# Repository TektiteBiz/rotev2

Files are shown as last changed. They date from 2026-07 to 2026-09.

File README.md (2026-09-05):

# RotEv2 FOC Library

## Install (PlatformIO)

Add to `platformio.ini`:

```ini
[env:myboard]
platform     = https://github.com/maxgerhardt/platform-raspberrypi.git
board        = generic_rp2350
board_build.core = earlephilhower
framework    = arduino
lib_deps     = https://github.com/TekiteBiz/rotev2.git
build_flags  = -std=gnu++17
```

---

## Dual-Core Contract

**The library owns core1.** The 24 kHz control ISR runs there and is started by `begin()`. Your
sketch runs on core0 (`setup()` / `loop()`).

**Do NOT define `setup1()` or `loop1()` in your sketch** — that conflicts with the library's core1
entry point.

---

## Quick Start

```cpp
#include <rotev.h>
using namespace rotev;

void setup() {
  Serial.begin(115200);
  begin();

  // 100 rad forward, cruising at 100 rad/s, reaching that in 0.5 s.
  Profile p = Profile::fromVelAccel(100.0f, 100.0f, 200.0f);
  p.print();

  motorEnable(MOTOR_1);
  motorSetProfile(MOTOR_1, p);
  ledColor(0, 0, 255);  // blue = running
}

void loop() {
  ProfileState st = motorProgress(MOTOR_1);
  Serial.printf("t %.2f s  pos %.1f rad  vel %.1f rad/s\n", st.t, st.pos, st.vel);
  if (st.done) ledColor(0, 255, 0);  // green = arrived
  delay(100);
}
```

See `examples/Basic/Basic.ino`.

---

## Profile

A `Profile` is a complete motion plan: a distance, and the velocity/acceleration envelope used to
cover it.

The shape is trapezoidal in velocity — constant acceleration up to the cruise speed, constant
speed, then constant deceleration back to rest — so position traces the familiar S. A move too
short to reach its cruise speed before it must start stopping degenerates to a triangle
(`cruiseTime() == 0`) at the same acceleration.

Distances are **signed**: a negative distance runs the move backwards. Velocity and acceleration
arguments are magnitudes.

### Constructing

```cpp
Profile();                                                        // empty, valid() == false
static Profile fromVelAccel(float distance, float max_vel, float max_accel);
static Profile fromTimeAccel(float distance, float time, float max_accel);
static Profile fromAccelDecel(float distance, float max_vel, float max_accel, float max_decel);
static Profile fromTimeAccelDecel(float distance, float time, float max_accel, float max_decel);
Profile scaleDistance(float k) const;
Profile scaleTime(float k) const;
```

- **`fromVelAccel(distance, max_vel, max_accel)`** — the usual one. Cover `distance` rad, never
  exceeding `max_vel` rad/s or `max_accel` rad/s². The duration falls out of the numbers.

  ```cpp
  Profile p = Profile::fromVelAccel(100.0f, 100.0f, 200.0f);  // ~1.5 s
  ```

- **`fromTimeAccel(distance, time, max_accel)`** — cover `distance` rad in exactly `time` seconds
  without exceeding `max_accel`. The cruise velocity is solved for. If `time` is shorter than the
  fastest move `max_accel` allows, you get that fastest move instead, and `duration()` is then
  larger than the `time` you asked for — check it if that matters.

  ```cpp
  Profile p = Profile::fromTimeAccel(100.0f, 2.0f, 200.0f);   // exactly 2 s
  ```

- **`fromAccelDecel(distance, max_vel, max_accel, max_decel)`** — the asymmetric complement to
  `fromVelAccel`: the ramp up runs at `max_accel` and the ramp down at `max_decel`. Useful when the
  axis can brake harder than it can drive (or the reverse). Passing the same rate twice reproduces
  `fromVelAccel` exactly.

  ```cpp
  Profile p = Profile::fromAccelDecel(100.0f, 100.0f, 100.0f, 400.0f);  // gentle start, hard stop
  ```

- **`fromTimeAccelDecel(distance, time, max_accel, max_decel)`** — the asymmetric complement to
  `fromTimeAccel`, with the same "too short a time gives you the fastest move instead" fallback.

  ```cpp
  Profile p = Profile::fromTimeAccelDecel(100.0f, 2.0f, 100.0f, 400.0f);
  ```

- **`scaleDistance(k)`** — vertical stretch of an existing profile. Same durations; distance,
  velocity, acceleration and deceleration all scale by `k`, so an asymmetric profile keeps its
  accel:decel ratio. A negative `k` reverses the move, which is how you build a return leg:

  ```cpp
  Profile back = p.scaleDistance(-1.0f);  // same envelope, opposite direction
  ```

- **`scaleTime(k)`** — horizontal stretch. Same distance; every duration scales by `k`, so
  velocity scales by `1/k` and both acceleration and deceleration by `1/k²`. `k` must be positive.

  ```cpp
  Profile gentle = p.scaleTime(2.0f);  // same move, twice as long, quarter the accel
  ```

### Multi-leg moves

```cpp
struct Leg {
  float dist;   // signed, rad
  float accel;  // magnitude, rad/s^2
  float decel;  // magnitude, rad/s^2
};

static bool fromLegs(const Leg* legs, int n, float time, Profile* out);
```

`fromLegs()` solves a whole sequence at once: it finds the single cruise velocity at which the legs,
run back to back, take exactly `time` seconds, and writes the resulting profiles to `out[0..n)`.
Each leg keeps its own accel and decel. Sharing one cruise velocity is what makes the sequence read
as one continuous move rather than n unrelated ones.

```cpp
const Leg legs[] = {{3.0f, 1.75f, 4.78f}, {7.0f, 1.0f, 1.75f}, {0.5f, 1.75f, 4.78f}};
Profile out[3];
if (!Profile::fromLegs(legs, 3, 9.9f, out)) { /* budget too tight -- see below */ }
```

```
leg1   3.00 rad v=1.3451 ta 0.769 tc 1.705 td 0.281  T 2.7554
leg2   7.00 rad v=1.3451 ta 1.345 tc 4.147 td 0.769  T 6.2611
leg3   0.50 rad v=1.1318 ta 0.647 tc 0.000 td 0.237  T 0.8835   <- pinned triangular
```

A leg too short to reach the shared velocity — leg 3 above, whose ramps meet at 1.132 rad/s — simply
runs flat out as a triangle and takes what it takes; the solver slows the other legs to absorb the
difference so the total still lands on the budget. Getting this wrong is subtle: a saturated leg's
duration stops responding to the cruise velocity entirely, so a solver that keeps crediting it with
the trapezoid formula lands a few milliseconds short.

The return value is **false** when `time` is below the flat-out total (every leg triangular at its
own limits). `out[]` is still filled, with that flat-out move — runnable, just slower than you asked
for — so you can check `duration()` to see what was actually possible. Degenerate input (`n <= 0`,
a null array, or a leg with a zero/non-finite distance, accel or decel) leaves every `out[]` entry
empty and returns false. Nothing is allocated; both arrays are caller-owned.

Bad arguments (zero, negative or non-finite distance/velocity/accel/time) produce an **empty**
profile rather than a fault: `valid()` is `false`, everything reads zero, and handing it to a
motor simply commands no motion.

### Querying

```cpp
float distance()    const;  // signed, radians
float duration()    const;  // seconds, accel + cruise + decel
float maxVelocity() const;  // signed peak (cruise) velocity, rad/s
float maxAccel()    const;  // signed peak acceleration, rad/s^2
float maxDecel()    const;  // signed peak deceleration magnitude, rad/s^2
float accelTime()   const;  // seconds
float cruiseTime()  const;  // seconds, 0 for a triangular profile
float decelTime()   const;  // seconds, == accelTime() only for a symmetric profile
bool  symmetric()   const;  // true when the two ramps take the same time
bool  valid()       const;  // false for an empty/degenerate profile
```

`maxVelocity()`, `maxAccel()` and `maxDecel()` carry the sign of the move, so they are the *actual*
peak values reached, not the magnitudes you passed in — for a triangular profile `maxVelocity()` is
below the `max_vel` you asked for. `maxDecel()` is a magnitude in the sense that the acceleration
actually reported during the ramp down is its negative: a profile decelerating at 400 rad/s² reads
`maxDecel() == 400` and `at(t).acc == -400` there.

### Sampling

```cpp
ProfileState at(float t) const;   // t clamped to [0, duration()]

struct ProfileState {
  float t;    // seconds since the profile started
  float pos;  // radians travelled (signed)
  float vel;  // rad/s (signed)
  float acc;  // rad/s^2 (signed)
  bool  done; // t >= duration()
};
```

`at()` evaluates the profile at any time without a motor being involved — useful for plotting or
for checking a move before committing to it. `t` is clamped, so `at(0)` is the start and any `t`
past the end returns the final position with zero velocity and `done == true`.

### Printing

```cpp
void print() const;
void printWithUnits(float wheel_radius, const char* unit) const;
```

`print()` dumps the profile to `Serial` in a readable block, in radians:

```
Profile: 100.000 rad in 1.500 s
  peak vel   100.000 rad/s (954.9 rpm) held 0.500 s
  peak accel 200.000 rad/s^2   peak decel 200.000 rad/s^2
  accel      0.500 s   cruise 0.500 s   decel 0.500 s
```

"held" is the time spent at peak velocity — the cruise time, `0.000` for a triangular profile.

`printWithUnits(wheel_radius, unit)` prints the same block converted to linear units, multiplying
every radian by `wheel_radius` and labelling it `unit`. The rpm figure is radius-independent and
stays. For a 16 mm wheel:

```cpp
p.printWithUnits(0.016f, "m");
```

```
Profile: 1.600 m in 1.500 s
  peak vel   1.600 m/s (954.9 rpm) held 0.500 s
  peak accel 3.200 m/s^2   peak decel 3.200 m/s^2
  accel      0.500 s   cruise 0.500 s   decel 0.500 s
```

An empty profile prints `Profile: <empty>` either way.

---

## Public API

All symbols are in `namespace rotev`. Include `<rotev.h>`.

### Initialization

```cpp
void begin();
```

Initializes GPIO, PWM, both ADCs, the LED and the buzzer, and starts the control loop on core1.
Call once from `setup()`.

### Motor

```cpp
void motorEnable(Motor m, bool enable = true);
void motorSetProfile(Motor m, const Profile& p);
Profile      motorProfile(Motor m);
ProfileState motorProgress(Motor m);
```

- **`motorEnable(m)`** — releases the driver's nSLEEP and lets the axis drive current. The axis
  then **holds position** even if it has never been given a profile: it is energised at standstill
  and resists being turned by hand. Standstill draws `MOTOR_HOLD_AMPS` (0.4 A), **not** the
  `MOTOR_AMPS` (0.9 A) a move uses — holding torque is therefore about 44% of moving torque.
  **If your application holds a load at standstill (a grade, a spring, a gripper, an arm), verify
  it still holds before updating: there is no position sensor, so a backdriven axis loses position
  silently and `motorProgress()` will still report the move completing normally.** Raise
  `MOTOR_HOLD_AMPS` in `constants.h` if your holding load needs it. There
  is no position sensor, so "position" means the commanded angle, which is 0 at boot — the first
  enable therefore pulls the rotor into alignment with electrical angle 0 rather than holding
  wherever it physically sits. `motorEnable(m, false)` zeroes the current and puts the driver back
  to sleep, leaving the shaft free.
- **`motorSetProfile(m, p)`** — starts `p` immediately, from wherever the axis currently is.
  Profiles are **relative**: the distance is measured from the position at the moment you call
  this, and the profile clock restarts at 0. Calling it again mid-move abandons the old profile
  and starts the new one from the current position. Setting a profile on a disabled motor stores
  it; it starts running when you enable the motor.
- **`motorProfile(m)`** — a copy of the profile currently executing.
- **`motorProgress(m)`** — where that profile is right now: elapsed time, position, velocity,
  acceleration, and whether it has finished. Poll `.done` to sequence moves.

When a profile finishes, the axis **holds**: velocity zero, angle frozen, still energised, so it
resists being pushed off target. Call `motorEnable(m, false)` to release it.

### LED

```cpp
void ledColor(uint8_t r, uint8_t g, uint8_t b);
```

Sets the RGB LED, 0–255 per channel (0 = off, 255 = full brightness).

### Buzzer

```cpp
void buzzerOn(uint16_t freq_hz);
void buzzerOff();
```

Drives the passive piezo buzzer at 50% duty. `freq_hz` is clamped to 1000–4000 Hz. Calling
`buzzerOn()` again while sounding retunes the frequency; you do not need `buzzerOff()` in between.

### Buttons

```cpp
bool buttonPressed(Button b);
```

`true` while the button is held.

### ADC and Bus Voltage

```cpp
float adcRead(AdcChannel ch);  // ADC_AIN1 / ADC_AIN2 / ADC_AIN3, volts
float busVoltage();            // volts
```

An on-board ADS1015 samples the motor bus voltage and the three user channels (AIN1–3) in the
background — there is nothing to start or poll. A timer started by `begin()` round-robins the four
channels, weighted so bus voltage refreshes at roughly 1 kHz (the control loop needs it) and each
user channel at roughly 330 Hz. Both calls return the most recent cached sample in volts and
are non-blocking.

### Enums

```cpp
enum Motor      : uint8_t { MOTOR_1 = 0, MOTOR_2 = 1 };
enum Button     : uint8_t { BTN_STOP = 0, BTN_GO = 1 };
enum AdcChannel : uint8_t { ADC_AIN1 = 0, ADC_AIN2 = 1, ADC_AIN3 = 2 };
```

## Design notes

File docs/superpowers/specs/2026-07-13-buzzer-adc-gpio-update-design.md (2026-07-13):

# RotEv2: Buzzer, ADS1015 ADC, GPIO Renumbering — Design Spec

**Date:** 2026-07-13
**Status:** Approved (brainstorming)
**Source PRD:** `docs/PRD.md` (updated 2026-07-13: buzzer, ADS1015 ADC, GPIO renumbering)
**Supersedes/extends:** `docs/superpowers/specs/2026-06-30-rotev2-foc-library-design.md`

## Overview

The PRD picked up three changes since the original FOC library design was implemented:

1. A passive piezo buzzer on GPIO4 (user on/off + frequency control).
2. An ADS1015 external I2C ADC (bus-voltage sensing for FOC inverse-park, plus
   3 user-facing channels).
3. GPIO renumbering: buttons/nSLEEP shifted by one pin, I2C1 (GPIO18/19) added
   for the ADC. Motor PWM pin naming/numbering (GPIO0-3) is unaffected — already
   correct in the current codebase.

This spec covers incorporating all three into the existing library structure
(`src/adc.cpp` = internal phase-current ADC stays as-is; a new `adc_ext.*`
module handles the ADS1015).

## Key Decisions

| Decision | Choice | Rationale |
|---|---|---|
| GPIO constants | Update `constants.h` only | No other file hardcodes raw pin numbers (verified). Mechanical change. |
| Buzzer PWM | Dedicated slice on GPIO4 (slice 2) | No aliasing with motor (slices 0/1) or LED (slices 4/7) slices. |
| ADS1015 driver | Single-shot mode, raw `hardware/i2c.h` on I2C1 @ 400kHz | Matches SDK-direct style used elsewhere in the codebase (no Arduino Wire). Single-shot gives explicit per-channel control needed for round-robin. |
| ADS1015 scheduling | Automatic background timer, not user-pumped | I2C1 is a dedicated bus (not user-facing — that's I2C0 on GPIO16/17), so there's no contention risk in making this fully automatic. Removes a footgun where a user forgets to pump a manual function and gets stale/wrong bus voltage feeding FOC. |
| Round-robin weighting | AIN0 (bus voltage): 2 of every 3 slots; AIN1/2/3 share the remaining slot in rotation | AIN0 effective rate ≈1.2-1.5kHz (meets "~1kHz" spec); user channels ≈150-250Hz each (ample for display/telemetry). |
| Vbus → FOC handoff | Same spinlock pattern as existing setpoint/telemetry cross-core state | Reuses proven mechanism; `controlStep` reads live `s_vbus` instead of constant `VBUS_V`. |
| Vbus startup fallback | Seed cache with nominal `VBUS_V` constant before first real sample | No special-cased startup logic needed in FOC; degrades gracefully. |
| User ADC API | `float adcRead(AdcChannel ch)`, returns cached volts, non-blocking | Matches existing telemetry-getter pattern (`motorCurrentA/B`). |
| Bus voltage API | `float busVoltage()` also exposed publicly | Needed by Phase 1 bringup to display/compare Vbus against a multimeter reading; also generally useful telemetry for any user sketch. |
| Buzzer API | `buzzerOn(uint16_t freq_hz)` / `buzzerOff()` | Frequency clamped [1000,4000]Hz; calling `buzzerOn` again while sounding retunes on the fly. |

## Architecture

### New/changed modules
- `constants.h` — updated pin numbers (`PIN_BTN_STOP=20, PIN_BTN_GO=21,
  PIN_NSLEEP_1=22, PIN_NSLEEP_2=23`), new `PIN_I2C1_SDA=18, PIN_I2C1_SCL=19,
  PIN_BUZZ=4`, new `AdcChannel` enum (`ADC_AIN1..3`).
- `src/buzz.h` / `src/buzz.cpp` (new) — PWM slice init/frequency retuning for GPIO4.
- `src/adc_ext.h` / `src/adc_ext.cpp` (new) — ADS1015 driver: init, background
  alarm callback + state machine, cached-value getters (`adcExtVbus()`,
  `adcExtUser(AdcChannel)`).
- `src/foc.cpp` — `controlStep` reads `adcExtVbus()` instead of the `VBUS_V`
  constant when computing `inversePark`/PI clamps. `VBUS_V` in `constants.h`
  becomes only the startup-fallback nominal value.
- `src/rotev.h` / `src/rotev.cpp` — new public functions: `buzzerOn`,
  `buzzerOff`, `adcRead`.
- `README.md` — updated GPIO/bus table, new Buzzer section, new ADC/AIN section.

### ADS1015 driver detail
- I2C1 @ 400kHz, raw `hardware/i2c.h` calls (`i2c_write_blocking`,
  `i2c_read_blocking` — each call is a few bytes, ~100-150µs, so blocking calls
  from within the alarm callback are acceptable and simple).
- Single-shot config per conversion: mux = target channel, PGA = ±4.096V FS
  (covers the 0-3.3V range of both the bus-voltage divider output and
  assumed user-signal range), data rate = 3300 SPS (fastest, ~303µs conversion).
- State machine (driven by a repeating hardware alarm on core0, registered in
  `adcExtInit()` called from `rotev::begin()`):
  - `START_CONV`: write 3-byte config register selecting the next channel in
    the weighted round-robin; record tick count.
  - `READ_RESULT`: once enough ticks have elapsed (≥ conversion time), read the
    2-byte conversion register, convert counts→volts, store into the
    appropriate cached slot (`s_vbus` for AIN0, `s_user[ch]` for AIN1-3) under
    the existing spinlock, advance round-robin, transition back to `START_CONV`.
  - Each alarm tick performs at most one of these steps — bounded, non-blocking
    from the caller's perspective (the alarm fires independently of user code).
- Round-robin sequence: `AIN0, AIN1, AIN0, AIN2, AIN0, AIN3, ...` (AIN0 every
  other slot = 2 of every 3 total slots across the 3-user-channel cycle).
- Counts→volts: `V = counts * (4.096 / 2048)` (single-ended 12-bit, ±4.096V FS
  in the ADS1015's 12-bit-left-justified single-ended convention).
- Bus voltage: `Vbus = adcExtVbus_divider_out * (7.3+2.2)/2.2` (undo the
  voltage divider) before caching into `s_vbus`.

### FOC integration
`controlStep()` (in `foc.cpp`) currently uses the compile-time `VBUS_V`
constant everywhere a bus voltage is needed (PI output clamps, `inversePark`
call). This changes to read `adcExtVbus()` once at the top of each
`controlStep()` invocation (a plain spinlock-guarded float read, same cost
profile as the existing setpoint read) and thread that value through instead
of `VBUS_V`. `VBUS_V` remains defined as the pre-ADC-sample fallback default.

## Public API additions (`namespace rotev`)
```cpp
void buzzerOn(uint16_t freq_hz);   // clamped to [1000, 4000] Hz, 50% duty
void buzzerOff();
float adcRead(AdcChannel ch);      // ADC_AIN1/2/3, last cached sample in volts, non-blocking
float busVoltage();                // last cached Vbus sample in volts, non-blocking
```
`AdcChannel` is a new enum in `constants.h`.

## Testing
- Buzzer: bringup smoke test (audible tone, frequency sweep) — no host-testable
  logic beyond clamping, which can get a small native unit test alongside the
  existing `test_foc_math` target.
- ADS1015 counts→volts and divider-undo math: pure functions, host-testable
  the same way as `foc_math`.
- Vbus feeding into FOC: validated on-hardware during bringup (compare
  measured Vbus via `adcRead`-style debug print against a multimeter reading
  of the actual bus rail).

## Documentation Deliverables
- `README.md` — updated GPIO/pin table (new button/nSLEEP/I2C1 numbers),
  new **Buzzer** section (range, API, 50% duty note), new **ADC** section
  documenting `adcRead()`, the 3 user channels, sample-rate expectations, and
  that bus-voltage sensing is automatic/internal (no user action needed).

## Bringup Impact (Phase 1)

Phase 1 (`bringup/phase1_hw.h`) is the first sketch to exercise the new hardware, so it gains two
additions:

- **Buzzer smoke test on GO:** pressing GO (in addition to turning the LED green) plays a short
  fixed tune via `buzzerOn`/`buzzerOff` calls (a few notes within the 1-4kHz range, each held
  briefly then silenced) before returning to the idle loop. This exercises the buzzer PWM path and
  gives an audible pass/fail signal without needing a scope.
- **Bus voltage telemetry:** the periodic serial print (alongside the four `motorCurrentA/B`
  traces) adds a fifth value, `rotev::busVoltage()`, so the operator can visually confirm it
  against a multimeter reading of the 12V rail.

`docs/BRINGUP.md` Phase 1 section (What to watch / Pass criteria / Failure modes table) is updated
to describe both additions.

## Open Assumptions to Confirm on Hardware
- ADS1015 I2C1 bus has adequate pull-ups on the PCB (dedicated bus, assumed
  fixed near the ADC — same assumption class as the existing I2C0 pull-up note
  in the PRD).
- PGA ±4.096V FS is adequate headroom for the bus-voltage divider output across
  the expected Vbus range; revisit if bringup shows clipping or poor resolution.

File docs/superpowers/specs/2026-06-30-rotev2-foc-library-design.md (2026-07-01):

# RotEv2 FOC Library — Design Spec

**Date:** 2026-06-30
**Status:** Approved (brainstorming)
**Source PRD:** `docs/PRD.md`

## Overview

RotEv2 is a PlatformIO/Arduino library for the Tektite RotEv2 PCB (RP2354 MCU). It
implements heavily optimized open-loop-position / closed-loop-current stepper FOC
for two 2-phase stepper motors, plus RGB LED and button support. It is published as
a conventional Arduino/PlatformIO library while internally using Pico SDK headers for
center-aligned PWM, timed ADC sampling, and dual-core scheduling.

## Key Decisions

| Decision | Choice | Rationale |
|---|---|---|
| Framework | earlephilhower arduino-pico core (import compatibility) with Pico SDK headers used internally | Users import as a normal Arduino/PlatformIO lib; internals get `<hardware/*.h>` for center-aligned PWM, ADC, DMA, IRQ. Verified RP2350/RP2354 (Pico 2) support. |
| Numerics | Single-precision `float` (M33 FPU) with standard `sinf`/`cosf` | Fast + readable; ~6200 cycles/loop @150 MHz vs a few hundred for trig. LUT only if bringup shows it doesn't fit. |
| Clock | Max validated clock; start 150 MHz, overclock target ~200 MHz confirmed in bringup | Timing constants derive from `clock_get_hz(clk_sys)`, never hard-coded. |
| Concurrency | FOC on **core1**, user code on **core0** | Real-time loop isolated from user code. Documented in README. |
| API style | Free functions in `namespace rotev` | Matches PRD examples; one fixed board. |
| ωe source | Differentiate commanded electrical angle + light LPF | Keeps `motorWrite(theta, current)` API exactly as PRD specifies. |
| Current sensing | INA186A3 (**100 V/V**), 15 mΩ shunt, REF 1.65 V → `V=1.65+1.5·I`, range ≈ ±1.1 A | Verified A3 = 100 V/V from TI datasheet. Current command clamped to ±1.1 A. |
| ADC oversampling | `ADC_OVERSAMPLE` default 4× per channel, burst centered on PWM midpoint | Rejects noise / boosts resolution while staying inside the center-aligned window (~16 µs burst). |
| Modulation | Direct αβ phase-voltage application via PH/EN (NOT SVPWM — that's 3-phase BLDC) | 2-phase stepper with two H-bridges; inverse-park voltages applied per phase. |
| LED polarity | Active-low (PWM on cathodes): pin high = off, pin low = on | Confirmed against board. |

## Hardware Reference

MCU: RP2354. GPIO map (from PRD):

| GPIO | Label | | GPIO | Label |
|---|---|-|---|---|
| 0 | ENA_2 | | 14 | LED.B |
| 1 | PHA_2 | | 19 | BTN_STOP |
| 2 | ENB_2 | | 20 | BTN_GO |
| 3 | PHB_2 | | 21 | nSLEEP_1 |
| 4 | ENA_1 | | 22 | nSLEEP_2 |
| 5 | PHA_1 | | 26 | SOB_1 (ADC0) |
| 6 | ENB_1 | | 27 | SOA_1 (ADC1) |
| 7 | PHB_1 | | 28 | SOB_2 (ADC2) |
| 8 | LED.R | | 29 | SOA_2 (ADC3) |
| 9 | LED.G | | | |

**User/bringup buses:**
- SPI1: GPIO10 SCK, 11 MOSI, 12 MISO, 13 CS — user-facing in production; **available for bringup debug**. `LOOP_TIMING_PIN` defaults to **GPIO10** during bringup.
- I2C0: GPIO16 SDA, 17 SCL — user-facing (board has pull-ups); not used in bringup.
- All bus pins may also serve as plain GPIO.

**Drivers:** Two motors, each with phase A and B. Each phase = one DRV8874 in PH/EN
mode + one INA186A3 inline current sensor (15 mΩ shunt, REF 1.65 V). `nSLEEP_1`
gates both motor-1 drivers; `nSLEEP_2` both motor-2 drivers.

**Motor (14HS11-1004):** 1.8°/step (200 steps/rev → **50 pole pairs**), phase R = 3.5 Ω,
L = 3.5 mH, rated 1.0 A.

**Buttons:** active-high, require internal pull-downs.

**RGB LED:** PWM on GPIO 8/9/14. **Active-low** — the PWM pins drive the LED
cathodes, so pin high = off, pin low = on. `LED_ACTIVE_HIGH = false`; a brightness
value of 255 = full on = pin held low (duty inverted internally).

## Architecture

### Packaging / layout
```
rotev2/
  library.json, library.properties, keywords.txt
  src/            rotev.h + internal modules
  examples/       short published usage sketches
  bringup/        self-contained PlatformIO project (lib_deps -> ../, own platformio.ini)
    phase1_hw/  phase2_openloop/  phase3_foc/  phase4_full/
  docs/PRD.md, docs/BRINGUP.md, docs/superpowers/specs/...
  README.md
```

### Modules (`src/`), each one focused unit
- `rotev.h` / `rotev.cpp` — public API (`namespace rotev`); thin, delegates to internals.
- `foc.*` — control loop: park / inverse-park, PI, lag comp. Runs on core1.
- `pwm.*` — center-aligned 24 kHz PWM setup; per-phase duty + direction (PH/EN).
- `adc.*` — ADC config, timed oversampled sampling, counts→amps.
- `hw.*` — pin map, `nSLEEP`, clock/overclock setup.
- `led.*` — RGB PWM.
- `button.*` — pull-down config + debounced reads.
- `debug.*` — `LOOP_TIMING_PIN` toggling (compile-time `ENABLE_LOOP_TIMING`).

### Dual-core model & data flow
- **core0:** user code + `rotev::` API.
- **core1:** real-time FOC; serviced by the 24 kHz PWM-wrap IRQ. Even/odd IRQs
  alternate motor 1 / motor 2 → **12 kHz per motor**.
- **Cross-core handoff:** `motorWrite` publishes `{theta, iq_cmd, enabled}` per motor
  into a shared struct; publication made atomic via an RP2350 hardware spinlock (or
  seqlock snapshot) so the ISR reads a consistent set. Telemetry (measured currents,
  estimated ωe) returns the same way for core0 logging/plotting.

## Control Loop

### PWM
- 4 phase EN pins → PWM slices, phase-correct (center-aligned), 24 kHz.
- `TOP = f_sys / (2 · 24000 · div)` (e.g. 3125 @150 MHz) → ~11–12-bit duty.
- One slice wrap IRQ = master 24 kHz tick on core1.

### Modulation (2-phase, direct αβ — NOT SVPWM)
SVPWM is a 3-phase BLDC technique and does not apply here. This is a 2-phase stepper
with two independent H-bridges: inverse-park yields the two phase voltages `Vα`
(phase A), `Vβ` (phase B) directly, and each is applied as a sinusoidal bipolar phase
voltage via `PH = sign(V)`, `EN duty = |V|/Vbus`. Open-loop phase current traces two
90°-shifted sine waves.

### ADC sampling
- Single SAR ADC, round-robin over the **active motor's two channels** only.
- Each channel sampled `ADC_OVERSAMPLE` (default 4×) in a tight burst, integer-
  accumulated then divided, then converted. Burst centered on the PWM midpoint (start
  ~half-a-burst before wrap so samples straddle center). ~16 µs @4×, inside budget.
  Drop to 2× if bringup shows the window too wide.
- `I = (counts/4095 · Vref − 1.65) / 1.5`; `Vref` isolated in one constant.

### Per-motor step (12 kHz, in ISR)
1. Read `Iα, Iβ` (measured; already αβ, no Clarke).
2. `θe = 50·θ_cmd`; estimate `ωe = 50·Δθ_cmd/Δt` with light LPF.
3. **Park** using commanded `θe` (open-loop position assumption) → `Id, Iq`.
4. **PI**: `kP = BW·L = 3.5`, `kI = BW·R = 3500` (BW = 1000 rad/s), anti-windup clamp.
   Setpoints `Id* = 0`, `Iq* = current command`.
5. **Lag comp**: `Uq = PIq(Iq*−Iq) + ωe·Ld·Id`, `Ud = PId(0−Id) − ωe·Lq·Iq`
   (Ld = Lq = 3.5 mH).
6. **Inverse Park** → `Vα, Vβ` → duty/PH. The 12 V bus assumption and all
   decoupling/feedforward live behind one `inversePark(Ud, Uq, θe, Vbus)` boundary so
   swapping in an ADC bus-voltage reading later is a one-line change.

Disabled motor: PI state reset, outputs zeroed, `nSLEEP` low.

### Debug timing pin
`LOOP_TIMING_PIN` (default GPIO10, bringup only) driven high on ISR entry, low on exit.
Scope it against PWM/current to measure per-loop compute time and sampling position.
`ENABLE_LOOP_TIMING` off in production frees the SPI1 pin.

## Public API (`namespace rotev`)
```cpp
void begin();                                   // clocks, pins, PWM, ADC, launch core1 FOC
void motorEnable(Motor m);                      // MOTOR_1 / MOTOR_2
void motorDisable(Motor m);
void motorWrite(float theta_rad, float amps, Motor m);   // position + q-current, amps clamped ±1.1A
void ledColor(uint8_t r, uint8_t g, uint8_t b);
bool buttonPressed(Button b);                   // BTN_STOP / BTN_GO
float motorCurrentA(Motor m), motorCurrentB(Motor m);    // last measured phase amps (telemetry)
```
`Motor` and `Button` are enums.

## Bringup (see `docs/BRINGUP.md` for full procedure)

Each phase is a sketch under `bringup/` with documented pass/fail vs scope/plotter.

- **Phase 1 — Basic HW:** enable/disable drivers, stream both phase currents, LED
  color on STOP/GO. *Pass:* sensible currents, buttons+LED respond, `nSLEEP` toggles.
- **Phase 2 — Open-loop SVPWM:** open-loop 60 RPM, voltage set for 0.1 A phase
  current; plot currents. *Pass:* two clean ~90°-shifted sine waves; timing pin shows
  stable 24 kHz.
- **Phase 3 — Closed-loop FOC (no lag comp):** PI current control, constant velocity /
  S-curve. *Pass:* Iq tracks setpoint, Id≈0, stable spin.
- **Phase 4 — Full library:** enable lag comp; S-curves to 100 rotations and 300 RPM.
  *Pass:* stable to 300 RPM, Id≈0 under speed (decoupling working), loop within budget.

## Documentation Deliverables
- `README.md` — library usage; full GPIO/bus map (incl. SPI1 GPIO10–13 & I2C0
  GPIO16–17); motor specs; PI tuning; current-sense range; dual-core note.
- `docs/BRINGUP.md` — phased procedure, what to look for, pass/fail.

## Testing
Real-time FOC validated on-hardware via bringup phases (no host harness for the ISR
path). Pure math helpers (park/inverse-park, scaling, ωe estimate) factored to be
host-testable for optional lightweight native tests.

## Open Assumptions to Confirm on Hardware
- Overclock target (~200 MHz) stability.

**Resolved:** ADC `Vref` = 3.3 V (confirmed); LED active-low with PWM on cathodes
(confirmed); modulation is direct αβ phase-voltage application, not SVPWM (confirmed).

## Workflow (per CLAUDE.md)
Feature branch, pre-feature tag, commit spec, per-phase validation against ground
truth before advancing; no direct work on `main`.

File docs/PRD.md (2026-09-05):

# rotev2 PRD
RotEv2 is a PlatformIO library meant specifically for the Tektite RotEv2 PCB and implements heavily optimized open-loop stepper FOC for both motors.

# Hardware
The library has 3 main functions exposed to the user:
- Stepper FOC control (via the drivers and current sensors)
- RGB LED
- Button detection
Documentation must be written in README.md outlining each function and explaining its use as well as the user-exposed GPIOs.

## MCU
MCU: RP2354
GPIO mappings: (GPIO #: label)
- 0: PWMA_2
- 1: PWMB_2
- 2: PWMA_1
- 3: PWMB_1
- 4: BUZZ
- 8: LED.R
- 9: LED.G
- 14: LED.B
- 18: I2C1_SDA
- 19: I2C1_SCL
- 20: BTN_STOP
- 21: BTN_GO
- 22: nSLEEP_1
- 23: nSLEEP_2
- 26: SOB_1
- 27: SOA_1
- 28: SOB_2
- 29: SOA_2

## Drivers
There are two stepper motors (motor 1 and motor 2). Each motor has phases A and B. Each phase has a DRV8874 motor driver set up with PH/EN mode, and a current sensor which is a INA181A2 with a 30mohm shunt and with REF biased to 1.65V. SOB_1 is the current output of the B phase of motor 1.

Each driver's EN pin is hardwired HIGH (pull-up on the PCB, no MCU connection) rather than GPIO-controlled. PH is driven by PWM (locked-antiphase: duty=(1+d)/2, d in [-1,1]), so current is always actively driven through the H-bridge rather than coasting -- this is the decay behavior FOC needs. For example, PHB_2 is the PWM pin on the B phase driver for motor 2. This replaced an earlier sign-magnitude scheme (EN-PWM, PH as static direction) that coasted instead of actively decaying; see Known Pitfalls.

nSLEEP is connected between each pair, so both drivers for motor 1 share nSLEEP_1 and both drivers for motor 2 share nSLEEP_2

## Buttons
The buttons go HIGH when pressed, so need the internal pull-down. 

## Buzzer
There is a passive piezo buzzer with a range of 1k-4khz on the BUZZ pin, apply a 50% duty cycle and adjust frequency. Make this user facing so the user can turn on and off the buzzer and set the frequency.

## RGB LED
The RGB LED will be controlled via PWM with the 3 pins. 

## Additional GPIOs
GPIOs 10, 11, 12, and 13 are meant for use by the user, but will also be used during bringup (explained later). These pins are the SPI1 bus, which must be documented in the readme. GPIOs 16 and 17 are I2C0 and feature I2C pull-ups on the board and are also exposed (but not used for bringup) and also must be documented in README.md. These pins serve as busses for the user but can also be used as general GPIO and not exclusively for SPI/I2C. The mappings when being used as a bus are as follows:
- 6, 7: General GPIO (PWM-capable)
- 10: SCK
- 11: MOSI
- 12: MISO
- 13: CS
- 16: SDA
- 17: SCL
- 24, 25: General GPIO, cannot do PWM since overlaps with LED PWM slice

## ADS1015 ADC
On I2C1 (GPIO 18/19) there is an ADS1015IRUGR ADC. AIN0 on this ADC is connected to bus voltage with a voltage divider with 7.3kohm on the high side and 2.2kohm on the low side. This needs to be sampled at ~1khz for the FOC loop inverse park. AIN1-3 are exposed to the user so consider how to display them to the user too.

The driver samples in a repeating-timer callback doing blocking I2C. Measured
in service the bus reads 12.12-12.17 V with a 0.07 V spread, i.e. neither sag
nor meaningful sampling noise, so the live value behaves like the 12.0 V
constant it replaced. Two caveats worth keeping in mind: the I2C return codes
are currently ignored, so a failed transaction writes uninitialised stack into
the cached voltage; and a bus voltage of 0 (drivers unpowered) sends
inversePark down its `inv = 0` path and trips the voltage backstop, so the FOC
is silently inert with driver power off.

# FOC
High frequency FOC will be implemented and run. The specifications are:
- 24kHz PWM frequency (with 12kHz control loop for each motor, alternating between motor 1 and motor 2)
- Need to be able to disable the control and each driver via nSLEEP (e.g. motorEnable(MOTOR_1) type of thing)
- The caller does not command position, velocity or current directly. It hands
  the ISR a motion PROFILE and the ISR executes it (`motorSetProfile(m, p)`).
  The profile computation has to happen inside the FOC tight loop: a commanded
  field generated on core0 is only as fine as the caller's loop rate and
  freezes for the whole of any caller stall, which lands directly on the field
  as torque ripple. Generating it on the hardware-timed control tick removes
  the caller's timing from the picture entirely.
- `Profile` (see `src/profile.h`) is trapezoidal in velocity -- constant
  acceleration to a cruise speed, then constant deceleration -- so the position
  it integrates to is the S curve. It is constructible from distance plus max
  velocity and acceleration, from distance plus a target time and acceleration,
  or by scaling an existing profile's distance or time.
- Current is fixed internally at `MOTOR_AMPS` (0.9 A) for moves and `MOTOR_HOLD_AMPS` (0.4 A) at standstill. Neither is exposed.
- The caller can read back the active profile (`motorProfile`) and its progress
  -- time, position, velocity, acceleration, done (`motorProgress`).
- Telemetry needed for bringup and tuning: per-motor phase currents, dq
  currents and applied dq voltages, plus live bus voltage. Without dq
  telemetry the loop is effectively unobservable -- see Known Pitfalls. This
  is not part of the user-facing API; it lives in `src/rotev_internal.h`.

Implementation-wise, there must be
- Center aligned PWM for SVPWM
- No clarke transform is needed since the currents are already in alpha-beta frame
- For park transform, assume the rotor is at the target position, and run PI control
- Run PI with pole placement, PER AXIS (the machine is salient, so a single
  gain cannot place both poles):
kP_d = BANDWIDTH * Ld
kP_q = BANDWIDTH * Lq
kI   = BANDWIDTH * R      (SHARED between the two axes)

kI is deliberately not split. Each axis must place its controller zero on its
own plant pole: the d-axis plant is 1/(Ld*s + R) with a pole at -R/Ld, so the
zero belongs at kI/kP_d = R/Ld, which falls out of kP_d = BW*Ld with a shared
kI = BW*R. The same holds for q. The saliency lives entirely in kP.

The motor specs are follows (write this in README):
- Part No: 14HS11-1004
- Step Angle: 1.8deg
- Phase Resistance: 3.5ohms  (datasheet -- WRONG, see below)
- Inductance: 3.5mH          (datasheet -- WRONG, see below)

### Measured motor parameters (these supersede the datasheet)

Both datasheet figures are wrong, and the inductance is wrong by more than 2x
in the direction that costs top speed. Bringup phase 5 measures them on real
hardware. The values below are the mean of two motors, which agreed to within
1.6% on R, 1.5% on Ld and 3.6% on Lq.

| Parameter | Measured | Datasheet |
|---|---|---|
| R (winding + Rds(on) + shunt) | 4.0417 ohm | 3.5 |
| Ld | 3.7946 mH | 3.5 |
| Lq | 8.2764 mH | 3.5 |
| saliency Lq/Ld | 2.16 - 2.20 | not given |

**The machine is salient.** Lq is ~2.2x Ld, which is expected for a hybrid
stepper -- the magnet sits in the d-axis flux path with mu_r ~ 1, making d the
high-reluctance axis -- but it means one inductance constant cannot describe
both axes. The datasheet's 3.5 mH is roughly Ld; nobody published Lq, and Lq
is the one that governs high-speed behaviour.

**Lq falls with current** (iron saturation), roughly 8.3 mH at 0.5 A trending
toward 6 mH at 1.0 A. The runtime therefore does not trust the constant: it
maintains a per-motor ONLINE Lq estimate from |ud|/(we*|iq|). PHASE_LQ only
seeds that estimate and sets kP_q and the decoupling feedforward.

**lambda_m (magnet flux) is NOT reliably measured.** The phase 5 extraction
returns a negative value with poor fit quality on both motors, and the two
motors disagree by 10x on it while agreeing to within 4% on everything else --
so the method is broken, not the motors. Do not use the printed Kt. Two
independent facts bound it instead: the 1700 RPM ceiling requires
lambda_m <= 0.67 mWb, hence Kt <= 0.033 N.m/A. That is far below what the
datasheet holding torque suggests, and it explains why the drive runs out of
torque so readily at low current.

Use the resistance and inductances for the PI tuning above.
Use bandwidth = ~160 Hz (so 1000 rad/s)

### Cross-coupling decoupling ("lag compensation")

Ud_compensation = −ωe · Lq · Iq
Uq_compensation = +ωe · Ld · Id

So in the end:
Uq = PIq(Iq_setpoint − Iq_measured) + ωe·Ld·Id_setpoint
Ud = PId(0 − Id_measured) − ωe·Lq·Iq_setpoint

**Feed these from the current COMMAND, never the measurement.** Using measured
Id/Iq closes a loop Ud -> Id -> Uq -> Iq -> Ud whose gain is
(we*Lq)(we*Ld)/(Zd*Zq); at speed Zd -> we*Ld and Zq -> we*Lq, so the gain
approaches exactly 1 -- marginally stable before the pipeline delay is even
counted -- and it multiplies current-sense ripple by we*Lq, which is 30 V/A at
690 RPM. Measured on hardware: the measured-current form dropped the ceiling
from 690 RPM to 550 RPM. Since Id_setpoint is always 0, only the d-axis term
survives in practice.

Note *why* this is needed, because it is not the usual reason. As a
DISTURBANCE the coupling is DC in the dq frame and the integrator rejects it
almost perfectly (~0.5 mA of error through a 2 s ramp), so deleting it looks
harmless at low speed and did in fact pass review once on that argument. It
matters because it couples the two regulators DYNAMICALLY: once we exceeds
BANDWIDTH the axes drive each other faster than either loop can respond. The
signature is unmistakable -- phase currents that are garbage while spinning
and a perfect sine the instant the rotor is stopped and we goes to zero.

Implement a tight loop with proper ADC sampling timing, proper center-aligned PWM, etc.

## Voltage limit, current derate, and the speed ceiling

On a 12 V bus this drive runs out of VOLTAGE long before it runs out of
current, and ud is what consumes it:

    ud = -we * Lq * iq          (uq measured only 0.8 V at 300 RPM, and falling)

The only lever on ud is iq, so the correct response to running out of voltage
is to command LESS CURRENT, not to throw torque away. Each control cycle:

    iq_max = UD_FRAC * vbus / (|we| * Lq_online) * trim   UD_FRAC = 0.83

This trades current for speed automatically, so the drive rides the voltage
limit rather than falling off it, and no hand-tuned current-per-speed table is
needed.

**The limit must be feedforward from speed, not feedback from measured ud.**
piStep already clamps its output to +-vbus, so |ud| can never be *observed*
exceeding the bus and a feedback version can never derate by more than
(1 - UD_FRAC). Measured on hardware: a feedback derate targeting 0.85 of the
bus actually delivered 0.995 and sat pinned at the backstop continuously.

A backstop still clamps |u| to vbus, scaling ud and uq TOGETHER so the applied
vector keeps its angle (an earlier version zeroed uq outright, which removed
all torque at exactly the speed where torque was needed and turned the ceiling
into a cliff). It must also pull the PI integrators down by the same factor:
piStep's anti-windup only sees its own per-axis +-vbus limit and cannot
observe the later scaling.

**The |u| <= vbus circle is correct here, not conservative.** Two independent
H-bridges do give a square limit reaching sqrt(2)*vbus on the diagonals, but
for a ROTATING vector va = |u|*cos(theta+phi) sweeps the full amplitude every
cycle, so |va| <= vbus requires |u| <= vbus. The square only helps a
stationary vector. The remaining lever on voltage is overmodulation (the
square-wave fundamental reaches 4/pi * vbus, ~27% more, at the cost of
deliberate harmonics), not a different clamp shape.

Measured behaviour: speed and current trade directly, rpm_max * iq ~= 280 at
0.5 A rising to ~370 at 1.0 A (the product is not constant because Lq
saturates). Lower current is monotonically faster until torque runs out;
below ~0.3 A the motor is torque-limited instead. With the derate active the
drive reached **1700 RPM**, against ~400 RPM before the parameters were
corrected.

## Control delay compensation

Current is sampled at the top of the ISR; the duty computed from it is applied
at the NEXT ISR for that motor and then held for a full tick, so the voltage
lands ~1.5 ticks after the measurement. At 700 RPM that is 125 us = 26
electrical degrees of stale angle, which rotates the applied vector backwards
and visibly distorts the phase currents. The inverse Park therefore runs at
theta_e + we*COMP_TICKS*dt, while the forward Park stays at the angle the
sample was actually taken at.

## Control-rate limit

The commanded field advances in steps of
(rpm/60)*360*POLE_PAIRS/(PWM_HZ/2) electrical degrees -- i.e. **rpm/40** at
24 kHz. FOC generally wants 20+ updates per electrical cycle; at 1700 RPM
there are only 8.5, which is why the current cannot look like a clean sine up
there regardless of voltage headroom. The only lever is PWM_HZ, traded against
ISR budget.

## Bringup
- The board will be brought up in phases (so make some test programs as a sub-folder that reference the library in the exterior folder that can be deployed to the board, can use development environments but it shouldn't interfere with the libraries use as a library)

### Phase 1: Basic hardware
Enable & disable motor drivers, log current sensing, change RGB LED color when stop/go pressed, etc. - no motion, just reading the sensors and ensuring basic hardware functionality

### Phase 2: Open-loop control
Do open-loop SVPWM with a voltage such that the phase current is 0.5A and spin the motors at 60RPM open-loop. Still log phase current and let it be graphed via arduino serial plotter. Should show up as two sine waves

(Originally spec'd at 0.1A -- raised to 0.5A after bringup showed 0.1A doesn't give
enough torque to overcome this motor's detent/static friction, so it just buzzes in
place instead of rotating even with a correct startup ramp. See Known Pitfalls.)

### Phase 3: Simple closed-loop FOC
Enable the PI controllers, constant velocity, on BOTH motors. Runs one long
profile whose cruise phase dominates, so the axis spends minutes at speed.

Because there is no position sensor, the loop park-transforms the measured
current onto the COMMANDED angle -- which is false at power-up, when the real
rotor angle is arbitrary. The velocity ramp from zero resolves this on its
own: for its first moments the commanded field is barely moving while already
carrying full current, which is exactly an alignment hold, and the rotor is
captured long before the speed is high enough to outrun it. A separate
explicit align stage was tried and removed as redundant.

Holding a stationary field at a known current is still the right way to check
the current-sense GAIN, since with the rotor still there is no back-EMF and no
di/dt and uq reduces to Ohm's law (`I_actual * R + V_offset`). That comparison
is what verified this board's sense chain to 0.3%, and it is worth repeating
on any new board before trusting a current number -- phase 5's alignment stage
does exactly this as its first step.

Logs loop rate, worst-case loop dt, electrical degrees per field step, bus
voltage min/max, and per-motor sensA/sensB/ud/uq/id/iq/derate.

### Phase 4: Full library
Trapezoidal position profile to 100 rotations on BOTH motors, peak 400 RPM,
via `motorSetProfile` (position authoritative + velocity feedforward).
Exercises the decoupling, the voltage derate and the delay compensation
together under acceleration.

### Phase 5: R / Ld / Lq characterization
Measures the motor parameters the datasheet gets wrong. Open-loop voltage
(`focSetVoltageAB`, no PI in the path) plus the existing current sense.

- **R** -- 6-point V/I sweep regressed as I vs V. Using the SLOPE rather than
  any single V/I point makes it immune to current-sense offset and to the
  driver's fixed dead-time drop; both land in the intercept, which is reported
  separately as a diagnostic.
- **Ld** -- step response with the rotor parked by DC current on phase B,
  which makes B the d-axis so the step produces zero torque and the rotor
  cannot move. Fitted by weighted least squares on ln(residual) vs t: the
  SLOPE carries tau, so the (variable, ~125 us) pipeline delay lands in the
  intercept and cancels. Weighting by r^2 and cutting the window at r > 0.15
  removes the Jensen bias of the log transform; 16 averaged captures take the
  spread to ~0.2%. Verified in simulation before being written to firmware.
- **Lq** -- CANNOT be measured at standstill: any q-axis current makes torque
  and the rotor moves, and it cannot be restrained by hand (the locked-rotor
  attempt returned R^2 0.95 with R_step 19% high). Measured instead on the
  SPINNING machine, where id is held at 0 and ud = -we*Lq*iq is a straight
  line through a 100-300 RPM sweep. R^2 0.9999.

Self-checks printed: R from the sweep vs R from the step (should agree to
~1%), fit R^2 for each, both regression intercepts (should be ~0), per-point
id during the speed sweep (off-zero means lost sync), and a raw CSV dump of
the averaged step captures so the exponential can be eyeballed.

Run from cold: the routine dissipates enough to warm the winding, and R
measurably tracks temperature at +0.39%/degC.

Document library use properly in README.md. Do everything with the consideration that this repository will be published as a platformio library.

## Known Pitfalls (learned during bringup)

These are hard-won findings from real hardware debugging. Read before touching PWM/GPIO init code.

### `pwm_set_mask_enabled()` overwrites the WHOLE PWM enable register
`pwm_hw->en` is a single register shared by every PWM slice on the chip (not per-slice). The
pico-sdk's `pwm_set_mask_enabled(mask)` does `pwm_hw->en = mask` — a blind overwrite, not a masked
set. If you build a mask containing only "the slices I care about" and call this, you will
silently **disable every other slice already running**, including the LED's PWM slices (GPIO
8/9 share slice 4, GPIO 14 is slice 7) if `ledInit()` ran first. This exact bug caused the RGB LED
to go stuck full-brightness ("white") the instant `focStart()`/`pwmInit()` ran, even though the
LED code itself was untouched and correct — it looked like an LED bug for a long time but was a
motor-PWM-init bug with an LED-shaped symptom. Always OR your mask into the existing register
(`pwm_hw->en |= mask;`) instead of overwriting it, so unrelated slices are left alone.

### GPIO-to-PWM-slice aliasing is real and easy to miss
Slice number = `(gpio >> 1) & 7` (for gpio < 32), channel = `gpio & 1`. Two GPIOs 16 apart, or an
even/odd pair like 8/9, can land on the *same* slice as different channels. `PIN_LED_R` (8) and
`PIN_LED_G` (9) are one such pair. `pwm_init()` resets the whole slice's counter-compare register
(both channels) every time it's called — so if two aliased pins are each `pwm_init`'d
independently, the second call clobbers the first pin's compare value. Init each unique slice
exactly once; only touch channel levels afterward via `pwm_set_gpio_level`/`pwm_set_chan_level`
(masked read-modify-write), never by re-running `pwm_init` on an already-configured slice.

### Diagnosing "firmware says X but hardware shows Y": read the actual registers
When a symptom contradicts what the code should be doing, don't keep guessing at the source —
print the raw peripheral registers (e.g. `pwm_hw->slice[N].csr`, `.cc`) directly over serial. This
is what actually found the enable-register bug above, after multiple plausible-sounding
software theories (LED slice aliasing, brownout/reset loops, hardware damage) were all
individually ruled out by hardware evidence and would have kept wasting time otherwise.

### `gpio_set_function(pin, GPIO_FUNC_PWM)` silently overrides an earlier SIO setup
`cfgSlice()`/`cfgEn()`-style helpers that call `gpio_set_function(pin, GPIO_FUNC_PWM)` change
*that specific pin's* mux, independent of anything `hwInit()` did earlier (`gpio_init` +
`gpio_set_dir` + `gpio_put`). During the first locked-antiphase experiment, a helper was reused
for its slice-init side effect on a pin that was supposed to stay a static GPIO output (motor 1's
EN pin, meant to be held HIGH) — but the helper also flipped that pin's own function to PWM with
its compare register left at 0 (permanent 0% duty), silently overriding the earlier `gpio_put(...,
1)`. Symptom: driver outputs stayed Hi-Z (disabled) the whole time — felt like inert detent
"braking" under hand rotation, not actual holding torque, with current telemetry reading ~0. Fix:
never assume a pin keeps whatever GPIO function `hwInit()` gave it — if a later init step touches
that pin's slice for any reason, explicitly re-assert the function/level you actually want
afterward, or (better, as done in the final design) restructure so nothing ever needs to touch a
pin's function twice with conflicting intents.

### A `volatile` struct field that is never copied out reads as stack garbage
`controlStep()` snapshots the shared `Setpoint` into a local under the spinlock,
one field at a time. Two fields (`ab_mode`, `vb_duty`) were never assigned — and
because the local is uninitialised, `if (sp.ab_mode)` was testing whatever was on
the stack. It consistently read false, so the direct-duty branch never ran and
execution silently fell through to the closed-loop PI, which then interpreted
`iq_cmd` as an amps command when the caller had stored a *duty* there. Every
caller of that mode commanded zero current and got zero current: phase 1c had
never worked as designed, and phase 5 initially reported `R = -72785 ohm`
because every point in its sweep measured no current at all. The user-visible
symptoms — nothing felt on the shaft, no supply draw — were the diagnosis; the
numbers were just an honest reading of a winding carrying nothing. Worth noting
this also invalidated the `ISENSE_SCALE` sign calibration, which had been
performed with phase 1c. When adding a field to a struct that is snapshotted
field-by-field, add the copy in the same commit, and prefer initialising the
local so a missed field fails loudly rather than plausibly.

### The setpoint refresh rate, not the ISR rate, quantizes the commanded field
The control ISR can only act on the angle the caller last handed it, so the
commanded field advances in steps of `(rpm/60)*360*POLE_PAIRS*T_caller`. A
`delayMicroseconds(500)` in the bringup loop meant 528 us per iteration, which
at 500 RPM is a **79 degree** electrical jump per update — a quarter cycle at a
time, not a rotating vector. It was plainly audible as clicking and roughness,
and it eats pull-out margin because the instantaneous load angle swings by half
the step. Deleting one delay line took the step to the ISR-rate floor of 12.5
degrees and the motor went "basically silent". Note the winding is a low-pass
(tau = L/R ~ 1 ms) so the *current* still looks like a decent sine while the
*command* is a coarse staircase — the scope will not show you this.

### The current waveform cannot tell you whether the rotor is turning
With no position sensor, the loop parks measured current onto the COMMANDED
angle, so the regulator produces a textbook rotating current vector whether the
rotor follows or sits dead still. It looks *better* when stalled, because a
stationary rotor generates no back-EMF and `uq` only has to supply `R*iq`. A
perfect sine at 400 RPM is therefore fully consistent with a stalled motor. Use
`uq` as the discriminator: back-EMF exists only if the rotor is moving, so a `uq`
near `R*iq` means stalled regardless of how clean the phase currents look. Hours
were spent debugging a current loop that was working correctly the whole time.

### Unbounded float angle accumulation stalls silently as the loop gets faster
`theta` accumulated without wrapping. Float resolution scales with magnitude, so
once theta passes ~5000 rad the per-iteration increment (2.6e-4 rad at 500 RPM
with a 5 us loop) vanishes into rounding entirely and the motor quietly stops
advancing. It was safe only because the loop was slow enough that the increment
was 100x larger — speeding the loop up is exactly what triggers it. `POLE_PAIRS`
is an integer, so wrapping mechanical angle at 2*PI is exactly 50 whole
electrical cycles and leaves `electricalAngle()` bit-for-bit unchanged. Phase 4's
profile position needs `double` for the same reason: its 628 rad target is where
float resolution (6e-5) approaches one iteration's increment.

### A clamped signal cannot be used as the feedback for a limiter
A current derate was built as feedback on `|ud|`, scaling the command by
`ud_lim/|ud|`. It could not work: `piStep` already clamps its output to
`+-vbus`, so `|ud|` never *exceeds* the bus and the ratio could never drop below
`UD_FRAC` — structurally incapable of derating more than 15% no matter how far
over budget the drive really was. Symptom: at 0.8 A it delivered 0.68 A where
~0.29 A was needed, and the ceiling barely moved. Before closing a loop around a
measurement, check whether anything upstream saturates it.

### Clamping after the regulator winds up integrators it cannot see
The `|u| <= vbus` backstop scales `ud`/`uq` *after* `piStep`, whose anti-windup
only knows its own per-axis limit. With `ud = -12.10` inside `+-12.16` the PI
believed it was unsaturated and kept integrating against a ceiling it had no way
to observe, while the applied voltage sat pinned at `|u| = vbus` continuously.
Any post-hoc actuator clamp has to be reported back to the regulator.

### Feedforward decoupling must use the command, not the measurement
See the FOC section: measured-current decoupling closes a loop whose gain
approaches exactly 1 at speed, and it dropped the measured ceiling from 690 RPM
to 550 RPM. This is a real trap because the textbook equations are written in
terms of Id/Iq and it is natural to reach for the measured values.

### Trust the datasheet for nothing you can measure
Phase resistance was 16% off (3.5 vs 4.04 ohm) and inductance was wrong by more
than 2x, in a direction that halved the current-loop bandwidth and doubled the
inductive voltage the loop fights at speed. The datasheet also never mentioned
that the machine is 2.2:1 salient, so a single inductance constant was wrong for
one axis no matter what value it held. Correcting these two numbers and
splitting the gains per axis took the ceiling from ~400 RPM to 560 RPM with no
hardware change; the rest of the path to 1700 RPM followed from measuring what
those parameters do under load.

### `Serial` is USB CDC on this core and blocks on 1 ms USB frames
The `115200` passed to `Serial.begin` is ignored. Writes block on USB frame
scheduling, so a telemetry print costs ~500-1000 us in bursts. When the caller
also owns the commanded angle, that stall lands directly in the motor as a
periodic angle jump — audible as regular clicking at the print rate (40 Hz for a
25 ms interval). Instrumentation that measures worst-case loop time will mostly
be measuring its own printing. Keeping the angle inside the ISR makes the
control path immune to it.

### Both ISENSE_SCALE values negative is a 180 degree frame rotation
`ISENSE_SCALE_A` and `ISENSE_SCALE_B` are both `-1`, which negates the whole
alpha-beta vector. That is a rotation, not a reflection, so it is harmless for
running the motor — torque is unaffected and the rotor simply sits 180
electrical degrees from where the model labels it — but it inverts the sign of
the back-EMF term and is why every `lambda_m` extraction returns negative. A
single flipped channel would be a reflection instead, which turns the dq
quantities into a 2*we signal the PI cannot track; the fact that `|i|` tracks its
command is what rules that out.

### Disabling a PWM slice freezes its output level; CC/CTR writes do not clear it
The PWM output flop only re-evaluates on a counter clock edge, and a slice with its `en` bit
cleared gets no clocks. So clearing `pwm_hw->en` leaves the pin latched at whatever level it
happened to hold, and the obvious follow-up — `pwm_set_gpio_level(pin, 0)` plus
`pwm_set_counter(slice, 0)` — does **nothing** to the pin, because neither write is a clock edge.
`buzzOff()` did exactly that and left BUZZ stuck high on roughly half of all calls (50% duty), a
steady 3.3V across the piezo, measurable with a multimeter after the sketch finished. The piezo is
capacitive so it draws no meaningful current, but the DC bias couples 3V3 rail ripple straight
across the diaphragm — heard as continuous hiss/static long after the last note — and the
diaphragm dumps its stored charge as an audible chirp when the board is powered down. The only way
to guarantee 0V is to take the pin away from the PWM block: `gpio_set_function(pin, GPIO_FUNC_SIO)`
with the pad driven low, and hand it back to `GPIO_FUNC_PWM` in `buzzOn()` only after the slice is
already toggling.

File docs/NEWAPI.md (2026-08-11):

# New API
The hardawre and general bringup described in PRD.md is fine, but some things need to be changed.

## Bringup
There are a lot of unnecesary logs in bringup. These require extra API methods and extra code in the API. Clean it up.

## README.md
README.md has a lot of unnecesary info for users. Like the hardware map, motor parameters, FOC tuning, etc. are useless for the user since they will always use this PCB and motor. Make sure it's only what's strictly needed in the API.

## Motor API
The motor API doesn't make sense anymore, since as you can see in phase 3 and 4 the actual profile computation has to occur in the FOC tight loop. Because of this, I want the API to be like the core0 just sends profiles over to core1 which executes them. 

All the weird motor commands go away. There is just `motorEnable` and `motorSetProfile`. Because of this you don't need to send over a position, velocity, accel number and then have code to pull the commanded position towards the target position - by computing the curve onbaord the loop it simplifies it a lot. The code in phase 3 and 4 should be vastly simplified for this.

(For phase 3 it's just a more relaxed profile with a really large distance value. As long as it will run for over 2 minutes at 1700rpm it's plenty long). Maybe phase 5 has to use some undocumented methods in the API.

Because the user can't calculate the profile directly, there should be lots of ways to construct the S curves. Here are some ways you should be able to construct the curve:
- Give distance, max velocity, and max acceleration
- Give distance, time, and max acceleration
- Give another profile and just scale the distance by some amount (like a vertical stretch)
- Give another profile and scale the time by some amount (like a horizontal stretch)

Each curve should also of course have a way of getting the time, the max velocity, the max accel, the time spent accelerating, decelerating, etc.

Add a print method that prints these in a nice easy to read manner in the serial terminal.

Everything will be in radians and seconds.

The user should be able to read the currently active profile (the actual profile object) and also read the progress of the profile (like current distance, time, velocity, acceleration, etc.). Make the current 0.8A always don't expose current to the user. 

## Messy code
In general there have been lots of changes bodged onto the original code in this repository leading to unclean, overly verbose code with lots of vestigial remnants, unused sections, unneeded features, and extra API methods. Simplify to the absolute max. The code in bringup phases 1-4 should be very very easy to read with the new API and super simple. (Phase 5 is of course complicated, that one is fine). Every file should getn inspected and refactored (and of course README has to be updated with the new motor API)

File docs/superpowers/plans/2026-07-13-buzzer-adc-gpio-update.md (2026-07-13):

# Buzzer, ADS1015 ADC, GPIO Renumbering Implementation Plan

> **For agentic workers:** REQUIRED SUB-SKILL: Use superpowers:subagent-driven-development (recommended) or superpowers:executing-plans to implement this plan task-by-task. Steps use checkbox (`- [ ]`) syntax for tracking.

**Goal:** Incorporate the PRD's buzzer, ADS1015 external ADC, and GPIO-renumbering changes into the
RotEv2 library: new pin map, a buzzer module, a background-timer-driven ADS1015 driver feeding live
bus voltage into the FOC loop and exposing 3 user channels, and updated bringup/docs.

**Architecture:** Two new self-contained modules (`buzz.*`, `adc_ext.*`) follow the existing
one-file-one-responsibility pattern (`led.*`, `button.*`). Pure conversion/clamping math is factored
into `foc_math.*` (host-testable, matching the existing `countsToAmps`/`ledDuty` precedent). Hardware
I/O (I2C, PWM registers, the background timer) lives in the new `.cpp` files and is verified by
on-target compilation, matching how `pwm.cpp`/`adc.cpp` are handled today (no host harness for
hardware-touching code).

**Tech Stack:** PlatformIO, Arduino core (earlephilhower) with Pico SDK headers (`hardware/pwm.h`,
`hardware/i2c.h`, `pico/time.h`), Unity test framework for the native/host test env.

## Global Constraints

- GPIO pins (from PRD, updated 2026-07-13): `BTN_STOP=20, BTN_GO=21, nSLEEP_1=22, nSLEEP_2=23,
  I2C1_SDA=18, I2C1_SCL=19, BUZZ=4`.
- Buzzer: passive piezo, range 1000-4000 Hz, 50% duty cycle, GPIO4.
- ADS1015 ADC on I2C1 (GPIO18/19): AIN0 = bus voltage via divider (7.3kΩ high side, 2.2kΩ low
  side), sampled at ~1kHz for FOC inverse-park. AIN1-3 exposed to the user.
- ADC scheduling: automatic background timer on core0 (per approved design spec
  `docs/superpowers/specs/2026-07-13-buzzer-adc-gpio-update-design.md`), not user-pumped. I2C1 is
  not a user-facing bus (that's I2C0 on GPIO16/17), so no contention risk.
- Round-robin weighting: AIN0 gets 2 of every 3 slots; AIN1/AIN2/AIN3 share the remaining slot in
  rotation. Sequence: `AIN0, AIN1, AIN0, AIN2, AIN0, AIN3` (repeating, length 6).
- ADS1015: single-shot mode, ±4.096V PGA FSR, 3300 SPS data rate, I2C address `0x48` (assumed
  ADDR pin tied to GND — flagged as an open assumption to confirm on hardware).
- Vbus fallback: seed with the existing `VBUS_V` nominal constant until the first real ADS1015
  sample lands; no special-cased startup branch elsewhere.
- Public API additions: `buzzerOn(uint16_t freq_hz)`, `buzzerOff()`, `float adcRead(AdcChannel ch)`,
  `float busVoltage()`.
- Phase 1 bringup gains: buzzer tune played on GO press, `busVoltage()` added to serial telemetry.
- Known Pitfall (must respect): never blind-overwrite `pwm_hw->en` — always OR-in or AND-out a
  single slice's bit (see `docs/PRD.md` "Known Pitfalls" and existing `src/pwm.cpp`).

---

### Task 1: GPIO/constants update + README pin table

**Files:**
- Modify: `src/constants.h:62-66`
- Modify: `README.md:132-159` (GPIO / Bus Map table)

**Interfaces:**
- Produces: `PIN_BTN_STOP`, `PIN_BTN_GO`, `PIN_NSLEEP_1`, `PIN_NSLEEP_2` (renumbered),
  `PIN_I2C1_SDA`, `PIN_I2C1_SCL`, `PIN_BUZZ` (new), `enum AdcChannel : uint8_t { ADC_AIN1=0,
  ADC_AIN2=1, ADC_AIN3=2 }` (new), `VBUS_DIV_HIGH_OHMS`, `VBUS_DIV_LOW_OHMS`, `ADS1015_FSR_V`,
  `BUZZ_MIN_HZ`, `BUZZ_MAX_HZ` (new constants used by later tasks).

- [ ] **Step 1: Update pin constants and add new constants in `src/constants.h`**

Replace lines 62-66 (the current `PIN_BTN_STOP`/`PIN_NSLEEP`/`PIN_SOx` block) with:

```cpp
constexpr uint32_t PIN_BTN_STOP = 20, PIN_BTN_GO = 21;
constexpr uint32_t PIN_NSLEEP_1 = 22, PIN_NSLEEP_2 = 23;
constexpr uint32_t PIN_SOB_1 = 26, PIN_SOA_1 = 27, PIN_SOB_2 = 28,
                   PIN_SOA_2 = 29;
constexpr uint32_t ADC_SOB_1 = 0, ADC_SOA_1 = 1, ADC_SOB_2 = 2, ADC_SOA_2 = 3;
constexpr uint32_t PIN_LOOP_TIMING = 10;  // SPI1 SCK; bringup only

// --- Buzzer (passive piezo, GPIO4) ---
constexpr uint32_t PIN_BUZZ = 4;
constexpr uint16_t BUZZ_MIN_HZ = 1000, BUZZ_MAX_HZ = 4000;

// --- ADS1015 external ADC (I2C1, GPIO18/19) ---
constexpr uint32_t PIN_I2C1_SDA = 18, PIN_I2C1_SCL = 19;
constexpr float ADS1015_FSR_V = 4.096f;          // PGA full-scale range used for all channels
constexpr float VBUS_DIV_HIGH_OHMS = 7300.0f;    // bus-voltage divider high side
constexpr float VBUS_DIV_LOW_OHMS = 2200.0f;     // bus-voltage divider low side

enum AdcChannel : uint8_t { ADC_AIN1 = 0, ADC_AIN2 = 1, ADC_AIN3 = 2 };
```

Note the pin numbers changed (`PIN_BTN_STOP` was 19, now 20; `PIN_BTN_GO` was 20, now 21;
`PIN_NSLEEP_1` was 21, now 22; `PIN_NSLEEP_2` was 22, now 23) — this matches the PRD's updated GPIO
map. `PIN_SOB_1`/`PIN_SOA_1`/`PIN_SOB_2`/`PIN_SOA_2`/`ADC_SOx`/`PIN_LOOP_TIMING` are unchanged, just
carried over verbatim.

- [ ] **Step 2: Compile-check the native test env (constants-only change, should be unaffected)**

Run: `pio test -e native`
Expected: all existing tests still PASS (this change doesn't touch any function under test, just
constants — confirms nothing else in `foc_math.cpp`/`constants.h` relies on the old pin numbers).

- [ ] **Step 3: Update the GPIO / Bus Map table in `README.md`**

Replace the table rows for BTN_STOP/BTN_GO/nSLEEP_1/nSLEEP_2 (lines 150-153) and the `4-7` row
(line 140), and insert a new I2C1 row, so the full table (lines 134-158) reads:

```markdown
| Signal | GPIO | Notes |
|---|---|---|
| PHA_2 | 0 | Motor 2 phase A PWM (DRV8874, locked-antiphase; EN hardwired HIGH) |
| PHB_2 | 1 | Motor 2 phase B PWM |
| PHA_1 | 2 | Motor 1 phase A PWM |
| PHB_1 | 3 | Motor 1 phase B PWM |
| BUZZ | 4 | Passive piezo buzzer, 1-4kHz, 50% duty |
| — | 5-7 | Free GPIO (6, 7 also usable as general-purpose PWM-capable user GPIO) |
| LED_R | 8 | Red, active-low PWM |
| LED_G | 9 | Green, active-low PWM |
| SPI1_SCK / LOOP_TIMING | 10 | SPI1 SCK; also bringup loop-timing pin |
| SPI1_MOSI | 11 | SPI1 MOSI (user bus) |
| SPI1_MISO | 12 | SPI1 MISO (user bus) |
| SPI1_CS | 13 | SPI1 CS (user bus) |
| LED_B | 14 | Blue, active-low PWM |
| I2C0_SDA | 16 | Board has pull-ups fitted (user bus) |
| I2C0_SCL | 17 | Board has pull-ups fitted (user bus) |
| I2C1_SDA | 18 | ADS1015 ADC (internal, not user-facing) |
| I2C1_SCL | 19 | ADS1015 ADC (internal, not user-facing) |
| BTN_STOP | 20 | Active-high, internal pull-down |
| BTN_GO | 21 | Active-high, internal pull-down |
| nSLEEP_1 | 22 | Motor 1 driver sleep (active-low) |
| nSLEEP_2 | 23 | Motor 2 driver sleep (active-low) |
| SOB_1 / ADC0 | 26 | Motor 1 phase B current sense |
| SOA_1 / ADC1 | 27 | Motor 1 phase A current sense |
| SOB_2 / ADC2 | 28 | Motor 2 phase B current sense |
| SOA_2 / ADC3 | 29 | Motor 2 phase A current sense |

SPI1 (GPIO 10–13) and I2C0 (GPIO 16–17) are routed to headers and are usable as plain GPIO when not
needed as buses. GPIO 24/25 are general GPIO but cannot do PWM (they overlap the LED PWM slice).
```

- [ ] **Step 4: Commit**

```bash
git add src/constants.h README.md
git commit -m "Update GPIO pin map for buzzer/ADC, add new constants"
```

---

### Task 2: Pure math helpers (buzzer clamp, ADS1015 conversion, round-robin sequencing)

**Files:**
- Modify: `src/foc_math.h`
- Modify: `src/foc_math.cpp`
- Modify: `test/test_foc_math/test_main.cpp`

**Interfaces:**
- Consumes: `BUZZ_MIN_HZ`, `BUZZ_MAX_HZ`, `ADS1015_FSR_V`, `VBUS_DIV_HIGH_OHMS`,
  `VBUS_DIV_LOW_OHMS` from `constants.h` (Task 1).
- Produces: `uint16_t buzzClampFreq(uint16_t freq_hz)`, `float adsRawToVolts(int16_t raw16)`,
  `float dividerToVbus(float v_div)`, `uint8_t adcSeqChannel(uint8_t seq_idx)`,
  `uint16_t adcConfigForChannel(uint8_t ch)` — all consumed by Task 3/4's hardware modules.

- [ ] **Step 1: Write the failing tests**

Add to `test/test_foc_math/test_main.cpp` (insert new test functions before `int main()`, after the
existing `test_led_duty_midpoint`):

```cpp
void test_buzz_clamp_within_range() {
  TEST_ASSERT_EQUAL_UINT16(2000, buzzClampFreq(2000));
}
void test_buzz_clamp_below_min() {
  TEST_ASSERT_EQUAL_UINT16(1000, buzzClampFreq(500));
}
void test_buzz_clamp_above_max() {
  TEST_ASSERT_EQUAL_UINT16(4000, buzzClampFreq(5000));
}
void test_ads_raw_to_volts_zero() {
  // raw16 = 0 -> 0V
  TEST_ASSERT_FLOAT_WITHIN(1e-5, 0.0f, adsRawToVolts(0));
}
void test_ads_raw_to_volts_positive_full_scale() {
  // 12-bit code 2047 (max positive), left-justified into upper 12 bits of 16-bit reg: 2047 << 4
  int16_t raw = (int16_t)(2047 << 4);
  TEST_ASSERT_FLOAT_WITHIN(0.01f, 2047.0f * (4.096f / 2048.0f), adsRawToVolts(raw));
}
void test_ads_raw_to_volts_negative() {
  // 12-bit code -1 (0xFFF), left-justified: 0xFFF0 as int16_t
  int16_t raw = (int16_t)0xFFF0;
  TEST_ASSERT_FLOAT_WITHIN(0.001f, -1.0f * (4.096f / 2048.0f), adsRawToVolts(raw));
}
void test_divider_to_vbus_matches_ratio() {
  // 12V bus -> divider output = 12 * 2.2/(7.3+2.2) = 2.7789...V -> undo should recover 12V
  float v_div = 12.0f * (2200.0f / (7300.0f + 2200.0f));
  TEST_ASSERT_FLOAT_WITHIN(0.01f, 12.0f, dividerToVbus(v_div));
}
void test_adc_seq_channel_weights_ain0() {
  // Sequence: AIN0, AIN1, AIN0, AIN2, AIN0, AIN3 (repeating, length 6)
  TEST_ASSERT_EQUAL_UINT8(0, adcSeqChannel(0));
  TEST_ASSERT_EQUAL_UINT8(1, adcSeqChannel(1));
  TEST_ASSERT_EQUAL_UINT8(0, adcSeqChannel(2));
  TEST_ASSERT_EQUAL_UINT8(2, adcSeqChannel(3));
  TEST_ASSERT_EQUAL_UINT8(0, adcSeqChannel(4));
  TEST_ASSERT_EQUAL_UINT8(3, adcSeqChannel(5));
  TEST_ASSERT_EQUAL_UINT8(0, adcSeqChannel(6));  // wraps
}
void test_adc_config_for_channel_selects_mux() {
  // Channel 0 (AIN0) config: OS=1, MUX=100, PGA=001, MODE=1, DR=111, COMP_QUE=11 -> 0xC3E3
  TEST_ASSERT_EQUAL_UINT16(0xC3E3, adcConfigForChannel(0));
  TEST_ASSERT_EQUAL_UINT16(0xD3E3, adcConfigForChannel(1));  // AIN1: MUX=101
  TEST_ASSERT_EQUAL_UINT16(0xE3E3, adcConfigForChannel(2));  // AIN2: MUX=110
  TEST_ASSERT_EQUAL_UINT16(0xF3E3, adcConfigForChannel(3));  // AIN3: MUX=111
}
```

Add the corresponding `RUN_TEST(...)` lines inside `main()`, right before `return UNITY_END();`:

```cpp
  RUN_TEST(test_buzz_clamp_within_range);
  RUN_TEST(test_buzz_clamp_below_min);
  RUN_TEST(test_buzz_clamp_above_max);
  RUN_TEST(test_ads_raw_to_volts_zero);
  RUN_TEST(test_ads_raw_to_volts_positive_full_scale);
  RUN_TEST(test_ads_raw_to_volts_negative);
  RUN_TEST(test_divider_to_vbus_matches_ratio);
  RUN_TEST(test_adc_seq_channel_weights_ain0);
  RUN_TEST(test_adc_config_for_channel_selects_mux);
```

- [ ] **Step 2: Run tests to verify they fail to compile/link (functions don't exist yet)**

Run: `pio test -e native`
Expected: FAIL — compile error, `buzzClampFreq`/`adsRawToVolts`/`dividerToVbus`/`adcSeqChannel`/
`adcConfigForChannel` not declared.

- [ ] **Step 3: Add declarations to `src/foc_math.h`**

Insert before the closing `} // namespace rotev` (after the existing `ledDuty` declaration):

```cpp
// Buzzer frequency clamp (see constants.h BUZZ_MIN_HZ/BUZZ_MAX_HZ).
uint16_t buzzClampFreq(uint16_t freq_hz);

// ADS1015 raw 16-bit register value (12-bit result left-justified) -> volts at
// the ±4.096V PGA setting used for every channel.
float adsRawToVolts(int16_t raw16);

// Undoes the 7.3k/2.2k bus-voltage divider to recover the actual bus voltage.
float dividerToVbus(float v_div);

// Weighted round-robin channel sequence for the ADS1015 background sampler:
// AIN0 gets 2 of every 3 slots (bus voltage needs ~1kHz; user channels don't).
// Returns 0=AIN0, 1=AIN1, 2=AIN2, 3=AIN3 for sequence index seq_idx (wraps mod 6).
uint8_t adcSeqChannel(uint8_t seq_idx);

// ADS1015 single-shot config register value (16-bit) to start a conversion on
// the given channel (0=AIN0..3=AIN3): OS=1 (start), PGA=+-4.096V, MODE=single-shot,
// DR=3300SPS, COMP_QUE=11 (comparator disabled).
uint16_t adcConfigForChannel(uint8_t ch);
```

- [ ] **Step 4: Implement in `src/foc_math.cpp`**

Insert before the closing `} // namespace rotev` (after the existing `ledDuty` definition):

```cpp
uint16_t buzzClampFreq(uint16_t freq_hz) {
  if (freq_hz < BUZZ_MIN_HZ) return BUZZ_MIN_HZ;
  if (freq_hz > BUZZ_MAX_HZ) return BUZZ_MAX_HZ;
  return freq_hz;
}

float adsRawToVolts(int16_t raw16) {
  int16_t code12 = raw16 >> 4;  // arithmetic shift preserves sign
  return (float)code12 * (ADS1015_FSR_V / 2048.0f);
}

float dividerToVbus(float v_div) {
  return v_div * (VBUS_DIV_HIGH_OHMS + VBUS_DIV_LOW_OHMS) / VBUS_DIV_LOW_OHMS;
}

uint8_t adcSeqChannel(uint8_t seq_idx) {
  static constexpr uint8_t kSeq[6] = {0, 1, 0, 2, 0, 3};
  return kSeq[seq_idx % 6];
}

uint16_t adcConfigForChannel(uint8_t ch) {
  // OS=1, MUX=100+ch, PGA=001 (+-4.096V), MODE=1 (single-shot), DR=111 (3300SPS),
  // COMP_MODE=0, COMP_POL=0, COMP_LAT=0, COMP_QUE=11 (disabled)
  uint16_t mux = (uint16_t)(4 + ch);  // 100..111
  return (uint16_t)(0x8000 |            // OS
                     (mux << 12) |
                     (0x1 << 9)  |      // PGA = 001
                     (0x1 << 8)  |      // MODE = single-shot
                     (0x7 << 5)  |      // DR = 111 (3300SPS)
                     0x3);              // COMP_QUE = 11
}
```

- [ ] **Step 5: Run tests to verify they pass**

Run: `pio test -e native`
Expected: PASS — all tests including the 9 new ones green.

- [ ] **Step 6: Commit**

```bash
git add src/foc_math.h src/foc_math.cpp test/test_foc_math/test_main.cpp
git commit -m "Add buzzer clamp and ADS1015 conversion/sequencing math with tests"
```

---

### Task 3: Buzzer module + public API

**Files:**
- Create: `src/buzz.h`
- Create: `src/buzz.cpp`
- Modify: `src/rotev.h`
- Modify: `src/rotev.cpp`

**Interfaces:**
- Consumes: `PIN_BUZZ` (Task 1), `buzzClampFreq` (Task 2).
- Produces: `void buzzInit()`, `void buzzOn(uint16_t freq_hz)`, `void buzzOff()` (internal); public
  `rotev::buzzerOn(uint16_t freq_hz)`, `rotev::buzzerOff()`.

- [ ] **Step 1: Create `src/buzz.h`**

```cpp
#pragma once
#include <cstdint>
namespace rotev {
void buzzInit();
void buzzOn(uint16_t freq_hz);
void buzzOff();
}
```

- [ ] **Step 2: Create `src/buzz.cpp`**

```cpp
#include "buzz.h"
#include "constants.h"
#include "foc_math.h"
#include "hardware/pwm.h"
#include "hardware/gpio.h"
#include "hardware/clocks.h"

namespace rotev {

// Fixed clkdiv chosen so TOP fits in the 16-bit PWM wrap register across the
// whole 1-4kHz buzzer range: at 200MHz sysclk / 8 = 25MHz PWM clock,
// TOP = 25MHz/1000Hz - 1 = 24999 (1kHz, largest TOP) down to 6249 (4kHz).
static constexpr float BUZZ_CLKDIV = 8.0f;

void buzzInit() {
  gpio_set_function(PIN_BUZZ, GPIO_FUNC_PWM);
  unsigned slice = pwm_gpio_to_slice_num(PIN_BUZZ);
  pwm_config c = pwm_get_default_config();
  pwm_config_set_clkdiv(&c, BUZZ_CLKDIV);
  pwm_config_set_wrap(&c, 0xFFFF);  // provisional; buzzOn sets the real wrap per frequency
  pwm_init(slice, &c, false);        // don't start; buzzOff() leaves it disabled
  pwm_set_gpio_level(PIN_BUZZ, 0);
}

void buzzOn(uint16_t freq_hz) {
  uint16_t f = buzzClampFreq(freq_hz);
  unsigned slice = pwm_gpio_to_slice_num(PIN_BUZZ);
  uint32_t pwm_clk = (uint32_t)(clock_get_hz(clk_sys) / BUZZ_CLKDIV);
  uint16_t top = (uint16_t)(pwm_clk / f - 1);
  pwm_set_wrap(slice, top);
  pwm_set_gpio_level(PIN_BUZZ, top / 2);  // 50% duty
  // Known Pitfall (docs/PRD.md): pwm_hw->en is a single register shared by every
  // slice -- never blind-overwrite it. OR in only this slice's bit.
  pwm_hw->en |= (1u << slice);
}

void buzzOff() {
  unsigned slice = pwm_gpio_to_slice_num(PIN_BUZZ);
  pwm_hw->en &= ~(1u << slice);
}

} // namespace rotev
```

- [ ] **Step 3: Add public API to `src/rotev.h`**

In `src/rotev.h`, add after the `setLagComp` declaration:

```cpp
void  buzzerOn(uint16_t freq_hz);  // clamped to [1000,4000] Hz, 50% duty
void  buzzerOff();
```

- [ ] **Step 4: Wire into `src/rotev.cpp`**

Add `#include "buzz.h"` to the includes at the top of `src/rotev.cpp`. In `begin()`, add
`buzzInit();` after `focStart();`:

```cpp
void begin() {
  hwInit();
  ledInit();
  focStart();
  buzzInit();
}
```

Add the two new public functions after `setLagComp`:

```cpp
void buzzerOn(uint16_t freq_hz) { buzzOn(freq_hz); }
void buzzerOff() { buzzOff(); }
```

- [ ] **Step 5: Compile-verify on target**

Run: `cd bringup && pio run -e phase1`
Expected: builds successfully (the library, including the new `buzz.cpp`, compiles as part of the
`symlink://../` lib dependency).

- [ ] **Step 6: Commit**

```bash
git add src/buzz.h src/buzz.cpp src/rotev.h src/rotev.cpp
git commit -m "Add buzzer module and public buzzerOn/buzzerOff API"
```

---

### Task 4: ADS1015 driver module + public API

**Files:**
- Create: `src/adc_ext.h`
- Create: `src/adc_ext.cpp`
- Modify: `src/rotev.h`
- Modify: `src/rotev.cpp`

**Interfaces:**
- Consumes: `PIN_I2C1_SDA`, `PIN_I2C1_SCL`, `VBUS_V` (fallback), `AdcChannel` (Task 1);
  `adsRawToVolts`, `dividerToVbus`, `adcSeqChannel`, `adcConfigForChannel` (Task 2).
- Produces: `void adcExtInit()`, `float adcExtVbus()`, `float adcExtUser(AdcChannel ch)`
  (internal); public `float rotev::adcRead(AdcChannel ch)`, `float rotev::busVoltage()`. Also
  consumed by Task 5 (`adcExtVbus()` used inside `foc.cpp`).

- [ ] **Step 1: Create `src/adc_ext.h`**

```cpp
#pragma once
#include "constants.h"
namespace rotev {
void  adcExtInit();          // configures I2C1 + starts the background sampling timer
float adcExtVbus();          // last cached bus voltage (volts), non-blocking
float adcExtUser(AdcChannel ch);  // last cached AIN1/2/3 sample (volts), non-blocking
}
```

- [ ] **Step 2: Create `src/adc_ext.cpp`**

```cpp
#include "adc_ext.h"
#include "foc_math.h"
#include "hardware/i2c.h"
#include "hardware/gpio.h"
#include "hardware/sync.h"
#include "pico/time.h"

namespace rotev {

static constexpr uint8_t ADS1015_ADDR = 0x48;   // assumes ADDR pin tied to GND
static constexpr uint8_t REG_CONFIG = 0x01;
static constexpr uint8_t REG_CONVERSION = 0x00;
// 3300 SPS -> ~303us conversion; wait 4 ticks @ 100us/tick = 400us margin.
static constexpr uint8_t CONV_WAIT_TICKS = 4;

static spin_lock_t* s_lock;
static float s_vbus;
static float s_user[3];

static repeating_timer_t s_timer;
static uint8_t s_seq_idx = 0;
static uint8_t s_wait_ticks = 0;
static bool s_waiting = false;  // false = need to start a conversion; true = waiting on it

static bool adcExtTimerCB(repeating_timer_t*) {
  uint8_t ch = adcSeqChannel(s_seq_idx);

  if (!s_waiting) {
    uint16_t cfg = adcConfigForChannel(ch);
    uint8_t buf[3] = { REG_CONFIG, (uint8_t)(cfg >> 8), (uint8_t)(cfg & 0xFF) };
    i2c_write_blocking(i2c1, ADS1015_ADDR, buf, 3, false);
    s_wait_ticks = 0;
    s_waiting = true;
    return true;
  }

  if (++s_wait_ticks < CONV_WAIT_TICKS) return true;

  uint8_t ptr = REG_CONVERSION;
  i2c_write_blocking(i2c1, ADS1015_ADDR, &ptr, 1, true);  // no stop -> repeated start
  uint8_t raw[2];
  i2c_read_blocking(i2c1, ADS1015_ADDR, raw, 2, false);
  int16_t reg = (int16_t)((raw[0] << 8) | raw[1]);
  float volts = adsRawToVolts(reg);

  uint32_t irq = spin_lock_blocking(s_lock);
  if (ch == 0) s_vbus = dividerToVbus(volts);
  else s_user[ch - 1] = volts;
  spin_unlock(s_lock, irq);

  s_seq_idx = (uint8_t)((s_seq_idx + 1) % 6);
  s_waiting = false;
  return true;
}

void adcExtInit() {
  i2c_init(i2c1, 400 * 1000);
  gpio_set_function(PIN_I2C1_SDA, GPIO_FUNC_I2C);
  gpio_set_function(PIN_I2C1_SCL, GPIO_FUNC_I2C);
  // No gpio_pull_up() calls: this is a dedicated internal bus (not the user-facing
  // I2C0), assumed to have fixed pull-ups near the ADS1015 on the PCB.

  s_lock = spin_lock_init(spin_lock_claim_unused(true));
  s_vbus = VBUS_V;  // fallback nominal until the first real sample lands
  s_user[0] = s_user[1] = s_user[2] = 0.0f;

  add_repeating_timer_us(100, adcExtTimerCB, nullptr, &s_timer);
}

float adcExtVbus() {
  uint32_t irq = spin_lock_blocking(s_lock);
  float v = s_vbus;
  spin_unlock(s_lock, irq);
  return v;
}

float adcExtUser(AdcChannel ch) {
  uint32_t irq = spin_lock_blocking(s_lock);
  float v = s_user[(int)ch];
  spin_unlock(s_lock, irq);
  return v;
}

} // namespace rotev
```

- [ ] **Step 3: Add public API to `src/rotev.h`**

Add after the `buzzerOff` declaration (from Task 3):

```cpp
float adcRead(AdcChannel ch);  // ADC_AIN1/2/3, last cached sample in volts, non-blocking
float busVoltage();            // last cached bus voltage in volts, non-blocking
```

- [ ] **Step 4: Wire into `src/rotev.cpp`**

Add `#include "adc_ext.h"` to the includes. In `begin()`, add `adcExtInit();` after `buzzInit();`:

```cpp
void begin() {
  hwInit();
  ledInit();
  focStart();
  buzzInit();
  adcExtInit();
}
```

Add the two new public functions after `buzzerOff`:

```cpp
float adcRead(AdcChannel ch) { return adcExtUser(ch); }
float busVoltage() { return adcExtVbus(); }
```

- [ ] **Step 5: Compile-verify on target**

Run: `cd bringup && pio run -e phase1`
Expected: builds successfully.

- [ ] **Step 6: Commit**

```bash
git add src/adc_ext.h src/adc_ext.cpp src/rotev.h src/rotev.cpp
git commit -m "Add ADS1015 driver with background sampling and public adcRead/busVoltage API"
```

---

### Task 5: Wire live bus voltage into the FOC loop

**Files:**
- Modify: `src/foc.cpp:1-108` (includes + `controlStep`)

**Interfaces:**
- Consumes: `adcExtVbus()` (Task 4).
- Produces: `controlStep` now uses a per-call live `vbus` instead of the `VBUS_V` constant; no
  change to `foc.h`'s public signatures.

- [ ] **Step 1: Add the include**

In `src/foc.cpp`, add `#include "adc_ext.h"` alongside the existing includes (after `#include
"adc.h"`).

- [ ] **Step 2: Read live Vbus at the top of `controlStep` and thread it through**

In `src/foc.cpp`, `controlStep` currently starts:

```cpp
static void __not_in_flash_func(controlStep)(Motor m, AB i) {
  Setpoint sp;
  bool lag;
  uint32_t irq = spin_lock_blocking(s_lock);
```

Change to:

```cpp
static void __not_in_flash_func(controlStep)(Motor m, AB i) {
  float vbus = adcExtVbus();
  Setpoint sp;
  bool lag;
  uint32_t irq = spin_lock_blocking(s_lock);
```

Then replace every remaining use of `VBUS_V` inside `controlStep` with `vbus`. Concretely, these
three lines:

```cpp
    uq = piStep(s_piq[m], sp.iq_cmd - dq.q, KP, KI, dt, VBUS_V);
    ud = piStep(s_pid[m], 0.0f      - dq.d, KP, KI, dt, VBUS_V);
```

become:

```cpp
    uq = piStep(s_piq[m], sp.iq_cmd - dq.q, KP, KI, dt, vbus);
    ud = piStep(s_pid[m], 0.0f      - dq.d, KP, KI, dt, vbus);
```

and:

```cpp
    float ud_mag = fabsf(ud);
    if (ud_mag > VBUS_V) {
      ud *= VBUS_V / ud_mag;
      uq = 0.0f;
    } else {
      float uq_budget = sqrtf(VBUS_V * VBUS_V - ud * ud);
```

becomes:

```cpp
    float ud_mag = fabsf(ud);
    if (ud_mag > vbus) {
      ud *= vbus / ud_mag;
      uq = 0.0f;
    } else {
      float uq_budget = sqrtf(vbus * vbus - ud * ud);
```

and finally:

```cpp
  AB v = inversePark(ud, uq, theta_e, VBUS_V);     // normalized duties [-1,1]
```

becomes:

```cpp
  AB v = inversePark(ud, uq, theta_e, vbus);       // normalized duties [-1,1]
```

Leave the `sp.openloop` branch's `uq = sp.iq_cmd;` line and everything in the `sp.ab_mode` branch
untouched — those don't reference `VBUS_V`. Also leave `focSetVoltageAB`/`motorWriteVoltageAB` (in
`rotev.cpp`) using the `VBUS_V` constant as-is — that's a separate bringup/testing helper (phase1c)
outside this change's scope; only the closed-loop `controlStep` path gets live Vbus.

- [ ] **Step 3: Compile-verify on target**

Run: `cd bringup && pio run -e phase1 -e phase2 -e phase3 -e phase4`
Expected: all four environments build successfully.

- [ ] **Step 4: Run the native test suite to confirm no regression**

Run: `pio test -e native`
Expected: PASS — `foc.cpp` isn't part of the native build filter, but this confirms nothing else
broke.

- [ ] **Step 5: Commit**

```bash
git add src/foc.cpp
git commit -m "Feed live ADS1015 bus voltage into the FOC control loop"
```

---

### Task 6: Phase 1 bringup additions (buzzer tune on GO, bus voltage telemetry)

**Files:**
- Modify: `bringup/phase1_hw.h`

**Interfaces:**
- Consumes: `rotev::buzzerOn`, `rotev::buzzerOff`, `rotev::busVoltage` (Tasks 3-4).

- [ ] **Step 1: Add the buzzer tune and bus voltage telemetry**

Replace the full contents of `bringup/phase1_hw.h` with:

```cpp
#pragma once
#include <Arduino.h>
#include <rotev.h>
using namespace rotev;

// Basic hardware verification: enable/disable the drivers, log idle phase
// currents and bus voltage, confirm the LED/buttons/buzzer work. No PWM is
// applied to the motor windings beyond what the driver requires to
// acknowledge enable.

static void playGoTune() {
  const uint16_t notes[] = {1000, 1500, 2000};
  for (uint16_t f : notes) {
    buzzerOn(f);
    delay(80);
  }
  buzzerOff();
}

void setup() {
  Serial.begin(115200);
  begin();
  motorEnable(MOTOR_1);   // nSLEEP high; no motion commanded
  motorEnable(MOTOR_2);
}

void loop() {
  bool go   = buttonPressed(BTN_GO);
  bool stop = buttonPressed(BTN_STOP);

  Serial.print(">motorCurrentA(MOTOR_1):"); Serial.print(motorCurrentA(MOTOR_1));
  Serial.print(",motorCurrentB(MOTOR_1):"); Serial.print(motorCurrentB(MOTOR_1));
  Serial.print(",motorCurrentA(MOTOR_2):"); Serial.print(motorCurrentA(MOTOR_2));
  Serial.print(",motorCurrentB(MOTOR_2):"); Serial.print(motorCurrentB(MOTOR_2));
  Serial.print(",busVoltage:"); Serial.println(busVoltage());

  if (go) { ledColor(0, 255, 0); playGoTune(); }
  if (stop) ledColor(255, 0, 0);
  delay(50);
}
```

- [ ] **Step 2: Compile-verify on target**

Run: `cd bringup && pio run -e phase1`
Expected: builds successfully.

- [ ] **Step 3: Commit**

```bash
git add bringup/phase1_hw.h
git commit -m "Add buzzer tune and bus voltage telemetry to Phase 1 bringup"
```

---

### Task 7: README documentation (Buzzer, ADC/AIN, Bus Voltage sections) + full verification

**Files:**
- Modify: `README.md`

**Interfaces:**
- None (documentation only).

- [ ] **Step 1: Add a Buzzer section to the Public API part of `README.md`**

Insert after the "### LED" section (after line 104, before "### Buttons"):

```markdown
### Buzzer

```cpp
void buzzerOn(uint16_t freq_hz);
void buzzerOff();
```

Drives the passive piezo buzzer on GPIO4 at 50% duty cycle. `freq_hz` is clamped to 1000-4000 Hz.
Calling `buzzerOn()` again while already sounding retunes the frequency without needing to call
`buzzerOff()` first.
```

- [ ] **Step 2: Add an ADC/AIN section**

Insert a new section after "### Current Telemetry" (after line 122, before "### Enums"):

```markdown
### External ADC (Bus Voltage + User Channels)

```cpp
float adcRead(AdcChannel ch);  // ADC_AIN1 / ADC_AIN2 / ADC_AIN3
float busVoltage();
```

An ADS1015 I2C ADC (on the internal I2C1 bus, GPIO18/19 — not user-facing) samples the motor bus
voltage (via a 7.3kΩ/2.2kΩ divider) and 3 user-facing channels (AIN1-3) in the background, fully
automatically — there is nothing to call or poll. A repeating timer started by `begin()` round-robins
the 4 channels, weighted so bus voltage updates at roughly 1kHz (needed internally by the FOC loop's
inverse-Park) while each user channel updates at roughly 150-250Hz (ample for telemetry/display use).
`adcRead()` and `busVoltage()` return the most recently cached sample in volts; both are
non-blocking.
```

- [ ] **Step 3: Update the `Enums` section** to include `AdcChannel`

In the "### Enums" section, add the new enum after `Button`:

```cpp
enum AdcChannel : uint8_t { ADC_AIN1 = 0, ADC_AIN2 = 1, ADC_AIN3 = 2 };
```

- [ ] **Step 4: Update the "Bus voltage is assumed to be 12V" line in the FOC/PI Tuning section**

Replace:

```markdown
Bus voltage is assumed to be **12 V** (used behind the inverse-Park transform to normalize duty cycle). This will be replaced by a live ADC read in a future revision.
```

with:

```markdown
Bus voltage is read live from the ADS1015 (`busVoltage()`, ~1kHz) and used behind the inverse-Park
transform to normalize duty cycle. A nominal 12V fallback is used only until the first real ADC
sample lands at boot.
```

- [ ] **Step 5: Full verification build**

Run each of the following and confirm all succeed:

```bash
pio test -e native
cd bringup && pio run -e phase1 -e phase1b -e phase1c -e phase2 -e phase3 -e phase4
```

Expected: native tests all PASS; all six bringup environments build without error.

- [ ] **Step 6: Commit**

```bash
git add README.md
git commit -m "Document buzzer, external ADC, and live bus voltage in README"
```

---

## Self-Review Notes

- **Spec coverage:** GPIO renumbering (Task 1), buzzer module + API (Task 3), ADS1015 driver +
  round-robin + Vbus feed + user channels (Tasks 2, 4, 5), Phase 1 bringup additions (Task 6),
  README docs (Task 7) — all sections of the design spec are covered.
- **Vbus fallback:** confirmed handled without special-casing (Task 4, `s_vbus = VBUS_V` at init).
- **`motorWriteVoltageAB`/`focSetVoltageAB`** intentionally left on the `VBUS_V` constant (Task 5
  note) — out of scope; it's a bringup-only direct-duty helper, not part of the closed-loop path
  the PRD asked to fix.
- **Type consistency:** `AdcChannel` defined once in `constants.h` (Task 1), used identically as
  the parameter type for `adcExtUser`/`adcRead` (Tasks 4, 7) — no renaming drift.

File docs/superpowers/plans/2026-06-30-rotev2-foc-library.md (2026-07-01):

# RotEv2 FOC Library Implementation Plan

> **For agentic workers:** REQUIRED SUB-SKILL: Use superpowers:subagent-driven-development (recommended) or superpowers:executing-plans to implement this plan task-by-task. Steps use checkbox (`- [ ]`) syntax for tracking.

**Goal:** Build a published PlatformIO/Arduino library for the Tektite RotEv2 PCB (RP2354) implementing dual-core, closed-loop-current / open-loop-position FOC for two 2-phase steppers, plus RGB LED and button support, validated through a 4-phase hardware bringup.

**Architecture:** Public free-function API in `namespace rotev` on core0; a real-time FOC control loop on core1 driven by a 24 kHz center-aligned PWM-wrap IRQ (alternating motors → 12 kHz each). Pure control math is isolated in a hardware-free `foc_math` unit (host-unit-tested with Unity); hardware modules use Pico SDK `<hardware/*.h>` headers.

**Bringup model:** the entire library **and** all four bringup programs are fully implemented before any hardware step-through. Each bringup phase is a separate PlatformIO **environment** (`phase1`…`phase4`) sharing one `main.cpp`. The operator flashes each env in order (`pio run -e phase1 -t upload`) and, per `docs/BRINGUP.md`, only ever tweaks **small documented sections** (a fixed set of tunable constants — overclock, oversample, sample instant, current sign, LED polarity, PI gains) when hardware reality requires it. No new code is written during bringup.

**Tech Stack:** C++17, earlephilhower arduino-pico core (RP2350/RP2354), Pico SDK (`hardware/pwm.h`, `hardware/adc.h`, `hardware/irq.h`, `hardware/clocks.h`, `pico/multicore.h`, `hardware/sync.h`), PlatformIO, Unity test framework (native env).

## Global Constraints

- **MCU / board:** RP2354; PlatformIO `board = generic_rp2350` (or Pico 2 variant), `board_build.core = earlephilhower`, `platform = raspberrypi` (maxgerhardt fork).
- **Language:** C++17. Public symbols live in `namespace rotev`. Enums: `Motor { MOTOR_1, MOTOR_2 }`, `Button { BTN_STOP, BTN_GO }`.
- **`foc_math` purity:** `src/foc_math.*` may include ONLY `<cmath>`, `<cstdint>`, `<cstddef>`. No Arduino/Pico headers — it must compile and unit-test under `platform = native`.
- **Concurrency contract:** the library owns core1 via `multicore_launch_core1`. User sketches MUST NOT define `setup1()`/`loop1()`. Documented in README.
- **Cross-core safety:** all core0↔core1 shared state passes through the spinlock-protected setpoint/telemetry structs in `foc.*`; no other shared mutable state.
- **Verbatim physical constants (motor 14HS11-1004):** pole pairs `POLE_PAIRS = 50` (1.8°/step); `PHASE_R = 3.5f` Ω; `PHASE_L = 0.0035f` H (Ld = Lq); rated 1.0 A.
- **Verbatim control constants:** `BANDWIDTH = 1000.0f` rad/s; `KP = BANDWIDTH * PHASE_L = 3.5f`; `KI = BANDWIDTH * PHASE_R = 3500.0f`.
- **Verbatim sensing constants:** `SHUNT_OHMS = 0.015f`; `INA_GAIN = 100.0f` (INA186A3); `ISENSE_REF_V = 1.65f`; `ADC_VREF = 3.3f`; `ADC_MAX = 4095.0f`; derived `VOLTS_PER_AMP = SHUNT_OHMS * INA_GAIN = 1.5f`; measurable range ≈ ±1.1 A → `IMAX_A = 1.1f` (current command clamp).
- **Verbatim PWM/loop constants:** `PWM_HZ = 24000`, per-motor loop 12 kHz (alternate); `ADC_OVERSAMPLE = 4` (default). PWM `TOP = clock_get_hz(clk_sys) / (2 * PWM_HZ)` (phase-correct), computed at runtime.
- **Verbatim GPIO map:** ENA_2=0, PHA_2=1, ENB_2=2, PHB_2=3, ENA_1=4, PHA_1=5, ENB_1=6, PHB_1=7, LED_R=8, LED_G=9, LED_B=14, BTN_STOP=19, BTN_GO=20, nSLEEP_1=21, nSLEEP_2=22, SOB_1=26/ADC0, SOA_1=27/ADC1, SOB_2=28/ADC2, SOA_2=29/ADC3. SPI1: SCK=10, MOSI=11, MISO=12, CS=13 (user; bringup debug). I2C0: SDA=16, SCL=17. `LOOP_TIMING_PIN = 10` (bringup only, behind `ENABLE_LOOP_TIMING`).
- **LED polarity:** active-low (PWM drives cathodes): brightness 255 = full on = pin held low; duty inverted internally.
- **Bus voltage:** `VBUS_V = 12.0f`, isolated behind `inversePark(...)` so a future ADC bus read is a one-line change.
- **Commit style:** commit after every green step. Never work on `main` — a feature branch + pre-feature tag is created before Task 1.
- **Bringup edits are bounded:** during hardware bringup the operator changes ONLY values listed in the `docs/BRINGUP.md` Tunable Knobs table (Task 16) — no library logic is rewritten. Every tunable is a single named constant or one clearly-marked line.
- **No vestigial code:** the shipped library must read as if written cleanly in one pass. Any exploratory/diagnostic/alternative code introduced while chasing a hardware result must be removed once the decision is settled — e.g., if `sinf`/`cosf` meets the timing budget, NO sin/cos LUT code exists anywhere (not commented-out, not `#if 0`, not an unused function); temporary probe logging is deleted; abandoned branches are removed. A path is either the chosen implementation or it is gone. `ENABLE_LOOP_TIMING` is the one intentional, documented compile-time seam and stays. Because this depends on bringup outcomes (which happen after all code is written, driven by the operator), it is enforced as the **Finalize** step in `docs/BRINGUP.md` (Task 16), NOT as an agent task — the agent-authored code already contains no LUT and no scaffolding by construction.

---

## File Structure

```
rotev2/
  platformio.ini              # native test env + rp2350 build env (for compile checks)
  library.json                # PlatformIO manifest
  library.properties          # Arduino manifest
  keywords.txt                # Arduino IDE highlighting
  src/
    rotev.h        rotev.cpp   # public rotev:: API (delegates to internals)
    constants.h                # all verbatim constants + Motor/Button enums (header-only)
    foc_math.h     foc_math.cpp# PURE math: park, inverse_park, PIState, omega estimator, adc scaling, led duty
    hw.h           hw.cpp      # clock/overclock, pin init, nSLEEP control
    pwm.h          pwm.cpp     # center-aligned 24kHz PWM setup + per-phase set(voltage, vbus)
    adc.h          adc.cpp     # oversampled 2-channel sampling + counts->amps
    foc.h          foc.cpp     # core1 launch, PWM-wrap ISR, per-motor control step, shared setpoint/telemetry
    led.h          led.cpp     # active-low RGB PWM
    button.h       button.cpp  # pull-down + debounced reads
    debug.h        debug.cpp   # LOOP_TIMING_PIN toggling
  examples/
    Basic/Basic.ino            # short published usage example
  bringup/
    platformio.ini             # self-contained project; 4 envs phase1..phase4 (each -DPHASE=N)
    src/main.cpp               # selects the phase header via -DPHASE
    phase1_hw.h  phase2_openloop.h  phase3_foc.h  phase4_full.h   # all fully implemented up front
  test/
    test_foc_math/test_main.cpp# Unity native unit tests for foc_math
  docs/PRD.md  docs/BRINGUP.md  docs/superpowers/...
  README.md
```

---

### Task 0: Branch, tag, and project scaffolding

**Files:**
- Create: `platformio.ini`, `library.json`, `library.properties`, `keywords.txt`, `src/constants.h`
- Test: `test/test_foc_math/test_main.cpp` (skeleton)

**Interfaces:**
- Produces: `constants.h` with all Global-Constraints constants and `enum Motor`, `enum Button`; a buildable `native` test env.

- [ ] **Step 1: Safety branch + tag**

```bash
cd /c/Users/bvikramadity/Development/nv/rotev2
git tag v0-pre-foc-library
git checkout -b feature/foc-library
```

- [ ] **Step 2: Write `library.json`**

```json
{
  "name": "RotEv2",
  "version": "0.1.0",
  "description": "Dual-core open-loop-position / closed-loop-current stepper FOC for the Tektite RotEv2 (RP2354).",
  "keywords": "foc, stepper, rp2350, rp2354, motor, control",
  "repository": { "type": "git", "url": "https://github.com/Nv7-Github/rotev2.git" },
  "frameworks": "arduino",
  "platforms": "raspberrypi",
  "headers": "rotev.h",
  "export": { "exclude": ["bringup", "docs", "test"] }
}
```

- [ ] **Step 3: Write `library.properties`**

```
name=RotEv2
version=0.1.0
author=Tektite
maintainer=Nv7-Github
sentence=Dual-core stepper FOC for the Tektite RotEv2 (RP2354).
paragraph=Open-loop-position / closed-loop-current field-oriented control for two 2-phase steppers, plus RGB LED and buttons.
category=Device Control
url=https://github.com/Nv7-Github/rotev2
architectures=rp2040
includes=rotev.h
```

- [ ] **Step 4: Write `platformio.ini`**

```ini
[env:native]
platform = native
test_framework = unity
build_flags = -std=c++17 -I src
build_src_filter = +<foc_math.cpp>

[env:rp2350]
platform = https://github.com/maxgerhardt/platform-raspberrypi.git
board = generic_rp2350
board_build.core = earlephilhower
framework = arduino
build_flags = -std=gnu++17
```

- [ ] **Step 5: Write `src/constants.h`**

```cpp
#pragma once
#include <cstdint>

namespace rotev {

enum Motor : uint8_t { MOTOR_1 = 0, MOTOR_2 = 1 };
enum Button : uint8_t { BTN_STOP = 0, BTN_GO = 1 };

// --- Motor 14HS11-1004 ---
constexpr int   POLE_PAIRS = 50;      // 1.8 deg/step -> 200 steps/rev
constexpr float PHASE_R    = 3.5f;    // ohms
constexpr float PHASE_L    = 0.0035f; // H (Ld = Lq)

// --- Control (PI pole placement) ---
constexpr float BANDWIDTH = 1000.0f;              // rad/s
constexpr float KP        = BANDWIDTH * PHASE_L;   // 3.5
constexpr float KI        = BANDWIDTH * PHASE_R;   // 3500

// --- Current sense (INA186A3, 15 mohm, REF 1.65V, 3.3V ADC) ---
constexpr float SHUNT_OHMS    = 0.015f;
constexpr float INA_GAIN      = 100.0f;
constexpr float ISENSE_REF_V  = 1.65f;
constexpr float ADC_VREF      = 3.3f;
constexpr float ADC_MAX       = 4095.0f;
constexpr float VOLTS_PER_AMP = SHUNT_OHMS * INA_GAIN; // 1.5
constexpr float IMAX_A        = 1.1f;                  // command clamp / sensor range

// --- PWM / loop ---
constexpr uint32_t PWM_HZ        = 24000;
constexpr int      ADC_OVERSAMPLE = 4;

// --- Bus voltage (future: from ADC) ---
constexpr float VBUS_V = 12.0f;

// --- GPIO map ---
constexpr uint32_t PIN_ENA_2 = 0,  PIN_PHA_2 = 1,  PIN_ENB_2 = 2,  PIN_PHB_2 = 3;
constexpr uint32_t PIN_ENA_1 = 4,  PIN_PHA_1 = 5,  PIN_ENB_1 = 6,  PIN_PHB_1 = 7;
constexpr uint32_t PIN_LED_R = 8,  PIN_LED_G = 9,  PIN_LED_B = 14;
constexpr uint32_t PIN_BTN_STOP = 19, PIN_BTN_GO = 20;
constexpr uint32_t PIN_NSLEEP_1 = 21, PIN_NSLEEP_2 = 22;
constexpr uint32_t PIN_SOB_1 = 26, PIN_SOA_1 = 27, PIN_SOB_2 = 28, PIN_SOA_2 = 29;
constexpr uint32_t ADC_SOB_1 = 0, ADC_SOA_1 = 1, ADC_SOB_2 = 2, ADC_SOA_2 = 3;
constexpr uint32_t PIN_LOOP_TIMING = 10; // SPI1 SCK; bringup only

} // namespace rotev
```

- [ ] **Step 6: Write Unity test `test/test_foc_math/test_main.cpp`**

Asserts real derived constants (verifies the native toolchain AND that `constants.h` compiles under `platform = native`). This file is replaced by the `foc_math` tests in Task 1.

```cpp
#include <unity.h>
#include "constants.h"
using namespace rotev;
void setUp() {}
void tearDown() {}
void test_derived_gains() {
  TEST_ASSERT_FLOAT_WITHIN(1e-4, 3.5f, KP);
  TEST_ASSERT_FLOAT_WITHIN(1e-4, 3500.0f, KI);
  TEST_ASSERT_FLOAT_WITHIN(1e-4, 1.5f, VOLTS_PER_AMP);
}
int main() {
  UNITY_BEGIN();
  RUN_TEST(test_derived_gains);
  return UNITY_END();
}
```

- [ ] **Step 7: Run native tests to verify the toolchain works**

Run: `pio test -e native`
Expected: PASS (1 test, `test_derived_gains`).

- [ ] **Step 8: Commit**

```bash
git add platformio.ini library.json library.properties keywords.txt src/constants.h test/
git commit -m "chore: scaffold RotEv2 library, manifests, constants, native test env"
```

---

### Task 1: FOC math — Park & inverse-Park transforms

**Files:**
- Create: `src/foc_math.h`, `src/foc_math.cpp`
- Test: `test/test_foc_math/test_main.cpp` (extend)

**Interfaces:**
- Produces:
  - `struct DQ { float d, q; };`
  - `struct AB { float a, b; };`
  - `DQ park(AB i, float theta_e);` — rotates αβ measured current into dq using electrical angle.
  - `AB inversePark(float ud, float uq, float theta_e, float vbus);` — dq voltages → αβ phase duties in **[-1, 1]** (normalized by `vbus`, clamped).

- [ ] **Step 1: Write failing tests for park/inversePark**

```cpp
#include <unity.h>
#include <cmath>
#include "foc_math.h"
using namespace rotev;

void setUp() {} void tearDown() {}

void test_park_zero_angle_is_identity() {
  DQ dq = park({1.0f, 0.5f}, 0.0f);
  TEST_ASSERT_FLOAT_WITHIN(1e-5, 1.0f, dq.d);
  TEST_ASSERT_FLOAT_WITHIN(1e-5, 0.5f, dq.q);
}
void test_park_ninety_deg_rotates() {
  // theta=pi/2: d = a*cos+b*sin = b ; q = -a*sin+b*cos = -a
  DQ dq = park({1.0f, 0.0f}, (float)M_PI/2);
  TEST_ASSERT_FLOAT_WITHIN(1e-4, 0.0f, dq.d);
  TEST_ASSERT_FLOAT_WITHIN(1e-4, -1.0f, dq.q);
}
void test_inverse_park_zero_angle_normalizes_by_vbus() {
  AB ab = inversePark(6.0f, 0.0f, 0.0f, 12.0f); // ud=6V of 12V -> 0.5
  TEST_ASSERT_FLOAT_WITHIN(1e-5, 0.5f, ab.a);
  TEST_ASSERT_FLOAT_WITHIN(1e-5, 0.0f, ab.b);
}
void test_inverse_park_clamps_to_unit() {
  AB ab = inversePark(24.0f, 0.0f, 0.0f, 12.0f); // 2.0 -> clamp 1.0
  TEST_ASSERT_FLOAT_WITHIN(1e-5, 1.0f, ab.a);
}

int main() {
  UNITY_BEGIN();
  RUN_TEST(test_park_zero_angle_is_identity);
  RUN_TEST(test_park_ninety_deg_rotates);
  RUN_TEST(test_inverse_park_zero_angle_normalizes_by_vbus);
  RUN_TEST(test_inverse_park_clamps_to_unit);
  return UNITY_END();
}
```

- [ ] **Step 2: Run tests to verify they fail**

Run: `pio test -e native`
Expected: FAIL — `foc_math.h` not found / undefined references.

- [ ] **Step 3: Write `src/foc_math.h`**

```cpp
#pragma once
namespace rotev {

struct DQ { float d, q; };
struct AB { float a, b; };

// Park: measured alpha-beta current -> dq at electrical angle theta_e.
DQ park(AB i, float theta_e);

// Inverse Park: dq voltage command -> normalized alpha-beta phase duty in [-1,1].
AB inversePark(float ud, float uq, float theta_e, float vbus);

} // namespace rotev
```

- [ ] **Step 4: Write `src/foc_math.cpp`**

```cpp
#include "foc_math.h"
#include <cmath>

namespace rotev {

static inline float clampf(float x, float lo, float hi) {
  return x < lo ? lo : (x > hi ? hi : x);
}

DQ park(AB i, float theta_e) {
  float c = cosf(theta_e), s = sinf(theta_e);
  return { i.a * c + i.b * s, -i.a * s + i.b * c };
}

AB inversePark(float ud, float uq, float theta_e, float vbus) {
  float c = cosf(theta_e), s = sinf(theta_e);
  float va = ud * c - uq * s;   // volts
  float vb = ud * s + uq * c;
  float inv = (vbus > 0.0f) ? 1.0f / vbus : 0.0f;
  return { clampf(va * inv, -1.0f, 1.0f), clampf(vb * inv, -1.0f, 1.0f) };
}

} // namespace rotev
```

- [ ] **Step 5: Add `foc_math.cpp` to the native build filter**

Confirm `platformio.ini` `[env:native]` has `build_src_filter = +<foc_math.cpp>` (from Task 0). No change needed if present.

- [ ] **Step 6: Run tests to verify they pass**

Run: `pio test -e native`
Expected: PASS (all park/inversePark tests).

- [ ] **Step 7: Commit**

```bash
git add src/foc_math.h src/foc_math.cpp test/
git commit -m "feat: park and inverse-park transforms with vbus normalization"
```

---

### Task 2: FOC math — PI controller with anti-windup

**Files:**
- Modify: `src/foc_math.h`, `src/foc_math.cpp`
- Test: `test/test_foc_math/test_main.cpp` (extend)

**Interfaces:**
- Produces:
  - `struct PIState { float integ; };`
  - `float piStep(PIState& s, float error, float kp, float ki, float dt, float out_limit);` — returns clamped output; integrator clamped to prevent windup (back-calculation: integrator not accumulated when output is saturated in the same direction).
  - `void piReset(PIState& s);`

- [ ] **Step 1: Write failing PI tests**

```cpp
void test_pi_proportional_only_first_step() {
  PIState s; piReset(s);
  // dt small so integral term tiny; kp=3.5, error=1 -> ~3.5 + ki*dt
  float out = piStep(s, 1.0f, 3.5f, 3500.0f, 1.0f/24000.0f, 1000.0f);
  TEST_ASSERT_FLOAT_WITHIN(0.01f, 3.5f + 3500.0f*(1.0f/24000.0f), out);
}
void test_pi_output_clamped_to_limit() {
  PIState s; piReset(s);
  float out = piStep(s, 100.0f, 3.5f, 3500.0f, 1.0f/24000.0f, 5.0f);
  TEST_ASSERT_FLOAT_WITHIN(1e-4, 5.0f, out);
}
void test_pi_antiwindup_stops_integrating_when_saturated() {
  PIState s; piReset(s);
  for (int i = 0; i < 1000; ++i) piStep(s, 100.0f, 3.5f, 3500.0f, 1.0f/24000.0f, 5.0f);
  // After saturation, a single negative error should immediately reduce output
  float out = piStep(s, -100.0f, 3.5f, 3500.0f, 1.0f/24000.0f, 5.0f);
  TEST_ASSERT_TRUE(out < 5.0f);
}
void test_pi_reset_clears_integrator() {
  PIState s; piReset(s);
  piStep(s, 1.0f, 3.5f, 3500.0f, 0.1f, 1000.0f);
  piReset(s);
  TEST_ASSERT_EQUAL_FLOAT(0.0f, s.integ);
}
```

Add the four `RUN_TEST(...)` lines to `main()`.

- [ ] **Step 2: Run to verify failure**

Run: `pio test -e native`
Expected: FAIL — `PIState`/`piStep`/`piReset` undefined.

- [ ] **Step 3: Extend `src/foc_math.h`**

```cpp
struct PIState { float integ; };
void  piReset(PIState& s);
float piStep(PIState& s, float error, float kp, float ki, float dt, float out_limit);
```

- [ ] **Step 4: Extend `src/foc_math.cpp`**

```cpp
void piReset(PIState& s) { s.integ = 0.0f; }

float piStep(PIState& s, float error, float kp, float ki, float dt, float out_limit) {
  float integ_next = s.integ + ki * error * dt;
  float unsat = kp * error + integ_next;
  float out = clampf(unsat, -out_limit, out_limit);
  // Anti-windup: only commit the integrator if we are not saturating further out.
  if (out == unsat) s.integ = integ_next;
  return out;
}
```

- [ ] **Step 5: Run to verify pass**

Run: `pio test -e native`
Expected: PASS.

- [ ] **Step 6: Commit**

```bash
git add src/foc_math.h src/foc_math.cpp test/
git commit -m "feat: PI controller with output clamp and anti-windup"
```

---

### Task 3: FOC math — electrical angle, ωe estimator, ADC scaling, LED duty

**Files:**
- Modify: `src/foc_math.h`, `src/foc_math.cpp`
- Test: `test/test_foc_math/test_main.cpp` (extend)

**Interfaces:**
- Produces:
  - `float electricalAngle(float theta_mech);` → `theta_mech * POLE_PAIRS`.
  - `struct OmegaEst { float prev_theta_e; float w_filt; bool primed; };`
  - `float omegaStep(OmegaEst& s, float theta_e, float dt, float alpha);` — returns low-pass-filtered electrical speed (rad/s); `alpha` is the LPF coefficient in (0,1].
  - `void omegaReset(OmegaEst& s);`
  - `float countsToAmps(uint16_t counts);` — `((counts/ADC_MAX)*ADC_VREF - ISENSE_REF_V) / VOLTS_PER_AMP`.
  - `float clampCurrent(float amps);` — clamp to ±`IMAX_A`.
  - `uint16_t ledDuty(uint8_t value, uint16_t top);` — active-low: returns `top - (value*top)/255`.

- [ ] **Step 1: Write failing tests**

```cpp
#include "constants.h"

void test_electrical_angle_scales_by_pole_pairs() {
  TEST_ASSERT_FLOAT_WITHIN(1e-4, 50.0f, electricalAngle(1.0f));
}
void test_omega_estimator_constant_velocity() {
  OmegaEst s; omegaReset(s);
  float dt = 1.0f/12000.0f, w = 0.0f;
  float theta = 0.0f;
  for (int i = 0; i < 500; ++i) { theta += 100.0f*dt; w = omegaStep(s, theta, dt, 0.05f); }
  TEST_ASSERT_FLOAT_WITHIN(1.0f, 100.0f, w); // converges toward 100 rad/s
}
void test_counts_to_amps_midscale_is_zero() {
  // 1.65V -> counts = 1.65/3.3*4095 = 2047.5
  TEST_ASSERT_FLOAT_WITHIN(0.01f, 0.0f, countsToAmps(2048));
}
void test_counts_to_amps_one_amp() {
  // V = 1.65 + 1.5 = 3.15 -> counts = 3.15/3.3*4095 = 3908.8
  TEST_ASSERT_FLOAT_WITHIN(0.01f, 1.0f, countsToAmps(3909));
}
void test_clamp_current_limits() {
  TEST_ASSERT_FLOAT_WITHIN(1e-5, 1.1f, clampCurrent(5.0f));
  TEST_ASSERT_FLOAT_WITHIN(1e-5, -1.1f, clampCurrent(-5.0f));
}
void test_led_duty_active_low() {
  TEST_ASSERT_EQUAL_UINT16(0, ledDuty(255, 3125));     // full on -> pin low
  TEST_ASSERT_EQUAL_UINT16(3125, ledDuty(0, 3125));    // off -> pin high
}
```

Add matching `RUN_TEST(...)` lines. Ensure `[env:native] build_flags` includes `-I src` (from Task 0) so `constants.h` resolves.

- [ ] **Step 2: Run to verify failure**

Run: `pio test -e native`
Expected: FAIL — new symbols undefined.

- [ ] **Step 3: Extend `src/foc_math.h`**

```cpp
#include <cstdint>

float electricalAngle(float theta_mech);

struct OmegaEst { float prev_theta_e; float w_filt; bool primed; };
void  omegaReset(OmegaEst& s);
float omegaStep(OmegaEst& s, float theta_e, float dt, float alpha);

float    countsToAmps(uint16_t counts);
float    clampCurrent(float amps);
uint16_t ledDuty(uint8_t value, uint16_t top);
```

- [ ] **Step 4: Extend `src/foc_math.cpp`**

```cpp
#include "constants.h"

float electricalAngle(float theta_mech) { return theta_mech * (float)POLE_PAIRS; }

void omegaReset(OmegaEst& s) { s.prev_theta_e = 0.0f; s.w_filt = 0.0f; s.primed = false; }

float omegaStep(OmegaEst& s, float theta_e, float dt, float alpha) {
  if (!s.primed) { s.prev_theta_e = theta_e; s.primed = true; return 0.0f; }
  float raw = (theta_e - s.prev_theta_e) / dt;
  s.prev_theta_e = theta_e;
  s.w_filt += alpha * (raw - s.w_filt);
  return s.w_filt;
}

float countsToAmps(uint16_t counts) {
  float v = ((float)counts / ADC_MAX) * ADC_VREF;
  return (v - ISENSE_REF_V) / VOLTS_PER_AMP;
}

float clampCurrent(float amps) { return clampf(amps, -IMAX_A, IMAX_A); }

uint16_t ledDuty(uint8_t value, uint16_t top) {
  uint32_t on = ((uint32_t)value * top) / 255u;   // desired brightness level
  return (uint16_t)(top - on);                      // active-low invert
}
```

- [ ] **Step 5: Run to verify pass**

Run: `pio test -e native`
Expected: PASS (all foc_math tests).

- [ ] **Step 6: Commit**

```bash
git add src/foc_math.h src/foc_math.cpp test/
git commit -m "feat: electrical angle, omega estimator, ADC scaling, active-low LED duty"
```

---
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

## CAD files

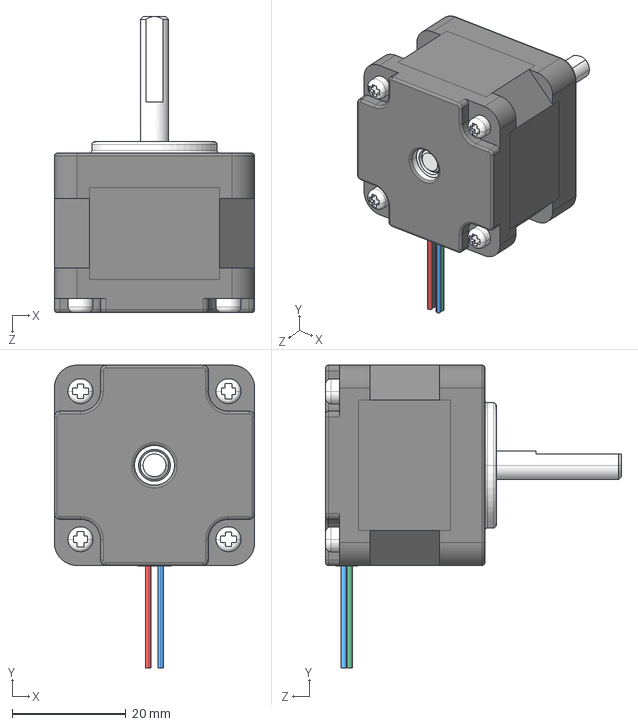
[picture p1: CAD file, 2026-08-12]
resources/14HS11-1004S.STEP
35.2 x 53.2 x 52.0 mm

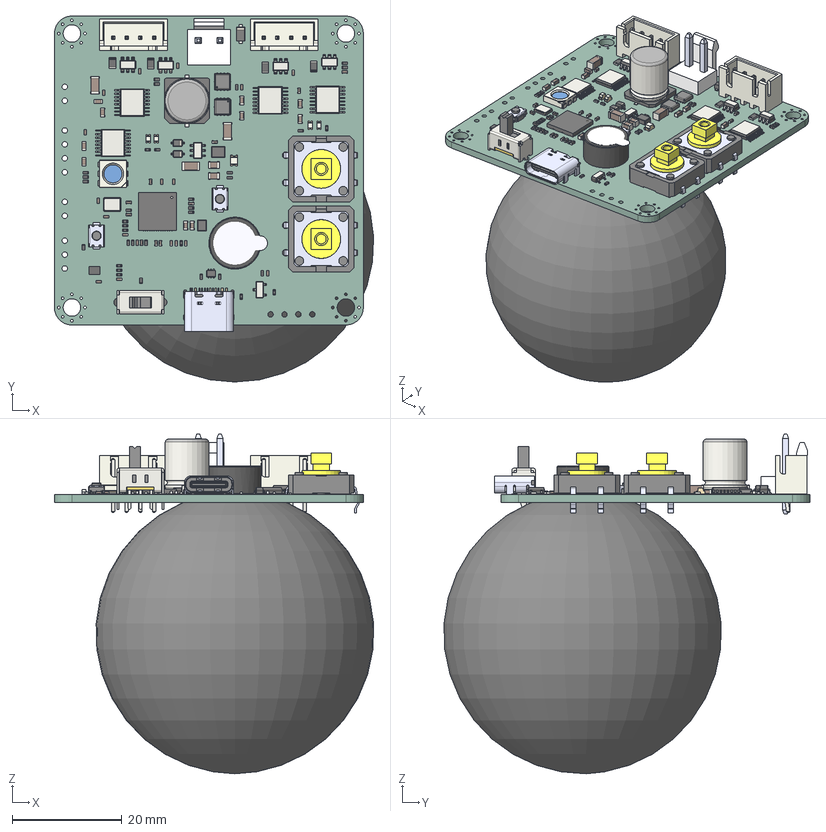
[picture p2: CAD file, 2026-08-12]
resources/rotev2.step
58.3 x 66.8 x 62.0 mm
C_0603_1608Metric_7
TYPE-C-31-M-12 x 42
C_0402_1005Metric_18
C_0402_1005Metric_25
AON7522E_1 x 7
R_0402_1005Metric_19
D_SOD_323
R_0402_1005Metric_26
R_0402_1005Metric_4
R_0402_1005Metric_25
C_1206_3216Metric
R_0402_1005Metric_9
R_0402_1005Metric_23
B3F-4055_1 x 7
R_0402_1005Metric_28
C_0402_1005Metric_16
SOT-23-6_1
B3F-4055 x 7
R_0402_1005Metric_3
TS-1088-AR02016_1 x 4
C_0402_1005Metric_2
R_0805_2012Metric_1
SOT-23
R_0402_1005Metric_33
B2P-VH(LF)(SN)_B2P-VH(LF)(SN) x 3
C_0402_1005Metric_24
LED_0603_1608Metric_Castellated_2
R_0402_1005Metric_14
LED_RGB_5050_6
R_0402_1005Metric_31
AON7522E x 7
AI-1027-TWT-3V-R
C_0402_1005Metric_7
TSOT-23-6
R_0402_1005Metric_32
R_0402_1005Metric_22
HTSSOP-16-1EP_4.4x5mm_P0.65mm_EP3.4x5mm_Mask2.66x2.46mm_3
LED_0603_1608Metric_Castellated_3
SW_Slide_SPDT_Straight_CK_OS102011MS2Q x 6
SOT-23-6_2
C_0402_1005Metric_3
C_0402_1005Metric_17
R_0402_1005Metric_1
C_0402_1005Metric_9
CP_Elec_8x10
C_0402_1005Metric_22
C_0402_1005Metric_4
R_0402_1005Metric_7
HTSSOP-16-1EP_4.4x5mm_P0.65mm_EP3.4x5mm_Mask2.66x2.46mm_2
C_0402_1005Metric_1
C_0402_1005Metric_12
C_0603_1608Metric
C_0402_1005Metric_6
C_0603_1608Metric_2
C_0402_1005Metric_8
LED_0603_1608Metric_Castellated
C_0603_1608Metric_1
SOT-23-6_3
rotev2_pcb_PCB
C_0402_1005Metric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

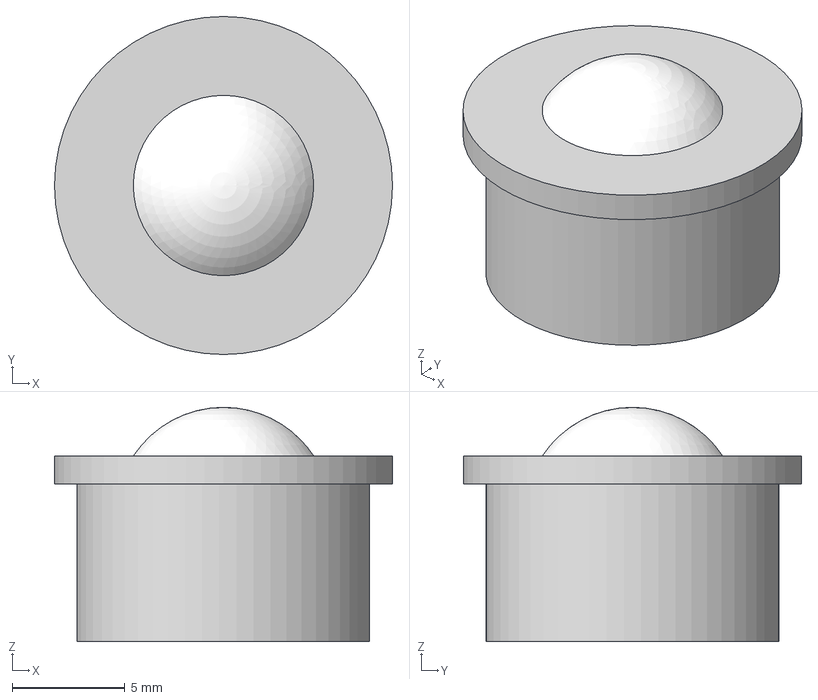
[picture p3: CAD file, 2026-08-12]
resources/NylonBall.step
15.0 x 15.0 x 10.4 mm

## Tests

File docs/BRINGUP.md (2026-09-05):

# RotEv2 FOC Library — Board Bringup Guide

This document is the step-by-step operator guide for bringing up the RotEv2 stepper FOC board.
Follow the phases in order — `phase1`, `phase1b`, `phase1c`, `phase2`, `phase3`, `phase4`, and the
`phase5` characterization run. Every phase builds on the last. If hardware deviates, consult the
Tunable Knobs table — it is the only place you should be editing values during bringup.

Phases 1b, 1c, 2 and 5 drive the inverter open-loop or read raw axis telemetry, which the public
API deliberately does not expose. They include `rotev_internal.h` for those primitives
(`motorSetVoltage`, `motorSetVoltageAB`, `motorSetVelocity`, `motorCurrent*`, `motorVoltage*`).
That header is for bringup only — application code uses `rotev.h` and nothing else.

---

## 1. How to Use This Guide

### 1.1 Prerequisites

- RP2350 board assembled, bus voltage at 12 V (VBUS), USB connected.
- PlatformIO installed (CLI or VS Code extension).
- Oscilloscope with at least two channels and at least 1 MHz bandwidth. Differential probes or
  a current-sense clamp are helpful for current waveforms.
- Serial terminal or Arduino Serial Plotter open at **115200 baud**.

### 1.2 Dual-Core Contract

The library owns **core1 exclusively**. The 24 kHz PWM wrap ISR (`pwmWrapISR`) is installed on
core1 and runs the FOC control loop there. Your sketch code — everything in `setup()` and `loop()`
— runs on core0. This split is mandatory:

- User sketches must **not** define `setup1()` or `loop1()`. Doing so will conflict with the
  library's `multicore_launch_core1` call and will produce undefined behavior.
- All cross-core communication between your `loop()` and the FOC loop is mediated by spin-locks
  inside the library. Never call FOC internals directly from setup1/loop1.

### 1.3 Flashing a Phase

All phase environments live in the `bringup/` subdirectory. Flash any phase with:

```
cd bringup
pio run -e phase1 -t upload   # or phase1b, phase1c, phase2, phase3, phase4, phase5
```

After upload, open the serial monitor (or Arduino Serial Plotter) in a second terminal:

```
pio device monitor
```

The monitor speed is fixed at **115200 baud** in `bringup/platformio.ini`.

### 1.4 Loop-Timing Pin (GPIO10)

The `phase1`, `phase2`, `phase3` and `phase4` environments define `ENABLE_LOOP_TIMING`. This causes `src/debug.h` to drive
**GPIO10** (SPI1 SCK) high at the start of `pwmWrapISR` and low at the end. Attach an
oscilloscope probe to GPIO10 and trigger on it to measure the ISR duration.

Expected characteristics:
- Pulse period: ~41.6 µs — the ISR fires at 24 kHz and GPIO10 pulses on every call. Each
  motor is serviced on every other call (12 kHz per motor), but you will see one pulse per
  41.6 µs on the scope, not one per 83.3 µs.
- Pulse width: the time consumed by one `controlStep()` call, including ADC sampling and PWM
  update. With the default settings this should be well under 20 µs.

Scope GPIO10 alongside a phase EN pin and a current waveform. If the pulse width approaches or
exceeds half the PWM period, consult the `OVERSAMPLE` and `SYSCLK` knobs and the flash-jitter
note in Section 3.

### 1.5 The Golden Rule

During bringup, **only adjust values listed in the Tunable Knobs table (Section 3)**. Do not
rewrite library internals to chase a symptom. The table maps every observable failure mode to
the one or two knobs that govern it.

### 1.6 Behavior Caveat: motorEnable and the Stored Profile

`motorEnable(m)` releases nSLEEP and lets the axis drive current; it commands no *motion* of its
own, but it does command a **hold**. An axis that has never been given a profile is energised at
standstill and resists being turned by hand — expect the shaft to feel locked, and expect the
first enable to snap the rotor into alignment with electrical angle 0, since with no position
sensor the commanded angle starts at 0 regardless of where the shaft actually is. A free shaft
after `motorEnable()` means the bridge is not driving; treat it as a fault, not as normal idle.

The order of `motorEnable()` and `motorSetProfile()` does not matter: a profile set on a disabled
axis is stored and its clock only starts once the axis is enabled, and a profile set on an axis
already holding replaces the hold.

Profiles are **relative** — the distance is measured from wherever the axis is when
`motorSetProfile()` is called, and the profile clock restarts at 0. Issuing a new profile mid-move
abandons the old one from the current position rather than queueing behind it.

Current is `MOTOR_AMPS` (0.9 A) for every closed-loop move and `MOTOR_HOLD_AMPS` (0.4 A) at standstill; neither is a knob. The
open-loop bringup phases command a voltage instead, so they set their own operating current
through Ohm's law.

### 1.7 Benign LED Boot Artifact

The LED may flash on for approximately 1 ms at power-up due to PWM init ordering. This is
harmless and disappears as soon as `ledInit()` completes.

---

## 2. Per-Phase Step-Through

### Phase 1 — Basic Hardware Verification (`phase1`)

**Purpose.** Confirm that the driver ICs, current sense amplifiers, buttons, and LED all work
before attempting any motor motion. No PWM is applied to the motor windings beyond what the
driver requires to acknowledge enable.

**Flash command.**

```
cd bringup && pio run -e phase1 -t upload && pio device monitor
```

**What to watch.**

Open the Arduino Serial Plotter. Five traces appear — `motorCurrentA(MOTOR_1)`,
`motorCurrentB(MOTOR_1)`, `motorCurrentA(MOTOR_2)`, `motorCurrentB(MOTOR_2)`, and
`busVoltage()` — printed at 50 ms intervals. Because the sketch commands 0 V explicitly after
enabling (`motorEnable()` would otherwise hold position at `MOTOR_AMPS`, which this phase must not
do with the loop still unverified), all four current traces should hover near 0 A, with only the
small ADC offset bias visible (the INA181A2
reference is 1.65 V; the ADC reads this as 0 A). With the motor unpowered the traces may wander by
a few milliamps due to common-mode and thermal noise; this is normal. `busVoltage()` should read
close to the actual 12 V rail (measure with a multimeter and compare).

Press **GO** (GPIO21). The LED should turn green, and the buzzer should play a short fixed tune
(a few notes, each within 1-4kHz, held briefly then silenced) via `buzzerOn`/`buzzerOff` — this is
the audible smoke test for the buzzer PWM path. Press **STOP** (GPIO20). The LED should turn red.

With a multimeter, measure `nSLEEP_1` (GPIO22) and `nSLEEP_2` (GPIO23). Both should be logic
HIGH (~3.3 V) after `motorEnable()` runs in `setup()`.

**Pass criteria.**

- All four current traces at idle: within ±few mA of 0 A.
- `busVoltage()` reads within a reasonable tolerance (e.g. ±0.5 V) of the multimeter-measured rail.
- GO button → LED green + audible tune; STOP button → LED red.
- `nSLEEP_1` and `nSLEEP_2` both measure logic HIGH after reset.

**Failure modes and knobs.**

| Symptom | Check / Knob |
|---|---|
| LED shows wrong color (red for GO, green for STOP) | Swap the `ledColor()` calls in `phase1_hw.h`, or check button wiring |
| LED is always on, always off, or wrong color hue | `LED-POL` — see `ledDuty` in `src/foc_math.cpp` |
| Current traces are offset by ±0.1 A or more | `VREF` — check `ADC_VREF` in `src/constants.h`; verify 1.65 V on the INA181A2 REF pins |
| Current traces show wrong polarity (positive when negative expected) | `ISENSE-SIGN` — swap SOA/SOB in `src/adc.cpp` or negate the result |
| `nSLEEP` pins remain low | Driver IC power supply missing; check 12 V rail and level-shifter |
| No tune plays on GO, or tune is inaudible/distorted | Check `PIN_BUZZ` (GPIO4) wiring; verify buzzer frequency is within its 1-4kHz rated range |
| `busVoltage()` reads 0, wildly wrong, or never updates | Check I2C1 (GPIO18/19) wiring/pull-ups to the ADS1015; verify the divider resistors (7.3k/2.2k) |

---

### Phase 1b — Open-Loop Voltage Spin (`phase1b`)

**Purpose.** First motion, with the PI bypassed. `motorSetVoltage(MOTOR_1, theta, UQ_VOLTS)`
applies a q-axis voltage directly through the inverse Park at a slowly rotating angle (5 RPM), so
the inverter, ADC timing and telemetry all run normally while nothing can wind up or saturate.
This is where current-sense sign, amplitude and channel assignment get confirmed before the loop
is closed.

**Flash command.**

```
cd bringup && pio run -e phase1b -t upload && pio device monitor
```

**What to watch.** Two traces, `sensA` and `sensB`: sinusoids ~90° apart with amplitude near
`UQ_VOLTS / PHASE_R`. Wrong polarity versus the commanded direction is the `ISENSE-SIGN` knob
(`ISENSE_SCALE_A` / `ISENSE_SCALE_B` in `src/constants.h`) — invisible open-loop but fatal
closed-loop, so fix it here.

---

### Phase 1c — Stationary DC Current (`phase1c`)

**Purpose.** The same open-loop voltage path as 1b, but at a FIXED electrical angle, so the whole
commanded voltage lands on phase A instead of sweeping across A/B. At DC the winding is purely
resistive, so `V = I * R` predicts the current exactly and the sense scale can be checked against
a number rather than a shape.

**Flash command.**

```
cd bringup && pio run -e phase1c -t upload && pio device monitor
```

**What to watch.** `sensA` should sit at `UQ_VOLTS / PHASE_R` (steady DC, not a sinusoid) and
`sensB` near zero. A scale error here is the `ISENSE-CAL` knob.

---

### Phase 2 — Open-Loop Sinusoidal Drive (`phase2`)

**Purpose.** Drive one motor open-loop at 60 RPM, still on `motorSetVoltage` — a fixed VOLTAGE
chosen so the resulting phase current is the phase's `TARGET_AMPS`, not a current command. Verify
that the Park/inverse-Park math and PWM generation produce the correct two-phase sinusoidal output
at speed, and that the control ISR meets its timing budget.

At 50 Hz electrical the inductive reactance is no longer negligible next to the winding
resistance, so the voltage is sized from `|Z| = sqrt(R^2 + (we*L)^2)`, not from R alone — the
sketch shows the arithmetic. The mechanical speed is also ramped from zero over `RAMP_TIME_S`: a
stepper rotor cannot snap to 50 Hz electrical from standstill, the field would outrun its pull-in
torque and it would buzz in place.

**Flash command.**

```
cd bringup && pio run -e phase2 -t upload && pio device monitor
```

**What to watch.**

In the Serial Plotter you will see two traces, `sensA` and `sensB`. At 60 RPM with 50 pole pairs,
the electrical frequency is:

```
f_electrical = 60 RPM * 50 / 60 = 50 Hz
```

The two current traces should appear as sinusoids approximately 90° apart (alpha and beta phases),
running at 50 Hz, with amplitude near the sketch's `TARGET_AMPS`. The exact amplitude depends on
motor back-EMF and winding impedance at this operating point; ±30% is acceptable, since the
voltage is computed from nominal R and L and nothing is regulating it.

On the oscilloscope, monitor GPIO10. The timing pulses should arrive at approximately 41.6 µs
intervals (24 kHz) with each pulse width comfortably inside 20 µs. A pulse that is much wider, or
that varies widely from cycle to cycle, indicates the ISR is overrunning or encountering flash
cache misses (see the `FLASH-TIMING` note in Section 3 and the SYSCLK/OVERSAMPLE knobs).

Observe the motor physically. It should rotate smoothly and continuously at approximately 60 RPM.
If the motor jitters, oscillates, or stalls, begin with the `PH-DIR` knob.

**Pass criteria.**

- Two sinusoidal current traces at ~50 Hz, ~90° apart, amplitude near `TARGET_AMPS`.
- GPIO10 pulse period ~41.6 µs; pulse width within budget (well under ~20 µs).
- Motor rotates smoothly at ~60 RPM.

**Failure modes and knobs.**

| Symptom | Check / Knob |
|---|---|
| Motor does not rotate; current traces flat or near-zero | `PH-DIR` — sign in `src/pwm.cpp` `pwmSetPhase`; also verify driver nENABLE logic |
| Motor buzzes in place instead of turning | `RAMP_TIME_S` in `phase2_openloop.h` — too short and the field outruns pull-in torque; `TARGET_AMPS` too low to beat detent torque |
| Motor steps roughly or oscillates at low speed | `CMD-DT` — `delayMicroseconds(500)` in `phase2_openloop.h`; reduce if the commanded angle is too coarse |
| GPIO10 pulse too wide or jittery | `OVERSAMPLE` (drop to 2) or `SYSCLK` (raise to 200000); see `FLASH-TIMING` note |
| Motor spins the wrong direction | `PH-DIR` — negate `duty_signed` or swap EN/PH pins in `src/pwm.cpp` |
| Current amplitude far above `TARGET_AMPS` | `ISENSE-SIGN` or `VREF` miscalibrated from Phase 1 |

---

### Phase 3 — Closed-Loop FOC, One Long Profile (`phase3`)

**Purpose.** Close the current loop and hold the board's top operating point for minutes. The
sketch builds ONE profile — a very long distance (25000 rad, ~4000 rotations) cruising at
1700 RPM after a ~2 s ramp — and hands it to both motors with `motorSetProfile()`. That is the
whole sketch: no ramp state machine and no elapsed-time accumulator on core0, because the control
ISR executes the profile itself.

At 1700 RPM the electrical frequency is:

```
f_electrical = 1700 RPM * 50 / 60 = 1417 Hz
```

which is the most demanding steady operating point the board sees. Current is fixed at
`MOTOR_AMPS` (0.9 A for moves; `MOTOR_HOLD_AMPS` = 0.4 A at standstill) and the voltage-limited derate is what keeps it there — at speed the drive
runs out of `ud = -we*Lq*iq` long before `uq`, so the derate trades current for speed rather than
letting the axis fall off the voltage limit.

The move takes about 2.4 minutes, which is the point: it is long enough to expose thermal drift,
integrator wind-up and any accumulating timing error.

**Flash command.**

```
cd bringup && pio run -e phase3 -t upload && pio device monitor
```

**What to watch.**

A small periodic print: profile time, each axis's commanded RPM, electrical degrees per control
step, bus voltage, and per-axis d/q currents and voltages. Watch for:

- `id` regulated near zero; `iq` near the 0.9 A command and falling once the `UD_FRAC` derate
  engages; `|ud|` riding just under its share of the bus once the axis is at speed.
- `degEStep` staying well under 90 (a quarter electrical cycle) — above roughly 20 degrees per
  step the current cannot look like a sine no matter how much voltage headroom there is.
- Phase currents are not in this print; scope them, or read `motorCurrentA/B` from
  `rotev_internal.h`, to confirm they stay smooth sinusoids through the ramp.
- Bus voltage sag under load — the derate sizes its limit against this number, so a dip costs real
  headroom.
- `motorProgress(m).done` staying false for the whole run, then the axes holding position.

On GPIO10, confirm the timing budget is still met at 1417 Hz electrical.

**Pass criteria.**

- Both motors reach and hold ~1700 RPM without stalling, hunting or audible pull-out.
- `id` stays near 0; no sustained oscillation or limit-cycling on either axis.
- The run completes without an overcurrent fault, nFAULT assertion or thermal shutdown.
- GPIO10 pulse width still within budget.

**Failure modes and knobs.**

| Symptom | Check / Knob |
|---|---|
| Sustained oscillation or limit-cycling | `KP` / `KI` — lower `BANDWIDTH` and let both recompute |
| Current tracks sluggishly, large steady-state error | `KP` / `KI` — raise `BANDWIDTH` |
| Motor pulls out (loses sync) partway up the ramp | Lengthen the profile's accel time — `Profile::scaleTime()` on the phase's profile, or a lower `max_accel`; check bus sag |
| Noisy current signals causing instability | `OVERSAMPLE` — raise (watch timing budget); also check for ground loops on SOA/SOB |
| ADC sampling hits a switching edge (spikes on current traces) | `SAMPLE-INSTANT` — shift the ADC burst offset in `src/foc.cpp` `controlStep` toward the PWM center |
| Motor stalls under load | `MOTOR_AMPS` — the fixed 0.9 A command; verify the hardware limit before raising |

---

### Phase 4 — Back-and-Forth Profiles (`phase4`)

**Purpose.** Exercise the profile API the way an application does: start, finish, reverse, repeat.
The forward leg is built once with `Profile::fromVelAccel()`; the return leg is
`fwd.scaleDistance(-1.0f)`, i.e. the same envelope mirrored. Each time `motorProgress(m).done`
goes true the sketch issues the other leg. That is the entire loop.

This is the harshest test of the drive because every cycle contains a full accel, a full decel and
a direction reversal through zero speed, where the commanded field and the rotor are least
constrained by each other.

**Flash command.**

```
cd bringup && pio run -e phase4 -t upload && pio device monitor
```

**What to watch.**

The periodic print shows the cycle count plus the same per-axis telemetry as phase 3. Over each
leg the current frequency should rise through the accel ramp, hold flat through cruise, and fall
back through decel; the reversal should be clean rather than a lurch. The motor must return to
where it started every second leg — mark the shaft and check it after several cycles, since a
position error that repeats per cycle accumulates visibly.

On GPIO10, the timing budget is tightest at peak speed — confirm the pulse width stays in budget
throughout, not just at cruise.

**Pass criteria.**

- The axes complete the configured number of forward/back cycles and stop on target, with the
  shaft mark back where it started (within a mechanical degree or so).
- Peak velocity reaches the profile's `maxVelocity()`; `motorProgress()` reports `done` at the end
  of each leg.
- No overcurrent fault, driver nFAULT assertion, or thermal shutdown.
- GPIO10 pulse width within budget throughout the full profile.

**Failure modes and knobs.**

| Symptom | Check / Knob |
|---|---|
| D-axis current grows significantly at high speed | Check `PHASE_LQ` in `src/constants.h` and `DECOUPLE_FRAC` (set 0 to A/B test the decoupling) |
| Shaft drifts from its start mark cycle after cycle | The axis is losing steps at the reversal or at peak speed, not accumulating profile error — the profile is exact. Lower peak velocity (`scaleTime()`) or check bus sag |
| Timing overrun at peak speed | `OVERSAMPLE` (drop to 2) or `SYSCLK` (raise the `set_sys_clock_khz` arg, e.g. 200000 = 200 MHz); see `FLASH-TIMING` note |
| Oscillation or instability at high speed | `KP` / `KI` — the plant changes at high electrical frequency; lower gains slightly |
| Hard stop / position error | `MOTOR_AMPS` not delivering enough torque, or the `UD_FRAC` derate cutting it back at speed; verify bus voltage and winding resistance |

---

### Phase 5 — Motor Characterization (`phase5`)

**Purpose.** Measure this motor's `PHASE_R`, `PHASE_LD` and `PHASE_LQ` rather than trusting the
datasheet, which is wrong on all three. Run it once per motor when a new motor type is fitted, and
put the results in `src/constants.h`; the measurement method and the values already there are
documented in that file's header comment.

This phase is the reason `rotev_internal.h` exists. It drives the inverter directly with
`motorSetVoltageAB()` for the DC and step-response measurements, uses `motorSetVelocity()` to
cruise at a fixed speed for the Lq sweep (and to re-align at theta 0 between stages), and reads
`motorCurrentD/Q()` and `motorVoltageD/Q()` for the regressions.

**Flash command.**

```
cd bringup && pio run -e phase5 -t upload && pio device monitor
```

**What to watch.** The sketch prints each stage's raw points and its regression result with an R².
Expect R² 0.998+ on the Ld step response and 0.999+ on the Lq sweep; a poor fit means the stage
did not hold its operating point, not that the motor is unusual.

The Lq sweep runs at `MOTOR_AMPS` (0.9 A), the same current every closed-loop move uses. NOTE the checked-in PHASE_LQ was characterised at 0.5 A, not at MOTOR_AMPS. Its
speed points are chosen against the pull-out ceiling at that current — roughly `rpm * iq ~ 280` on
a 12 V bus — so raising them without lowering the current will pull the rotor out mid-sweep and
poison the fit.

---

## 3. Tunable Knobs Reference

These are the **only** values an operator should edit during bringup. Everything else in the
library is structural code that should not be changed without a design review.

| ID | Knob | File / Location | Default | When to Change |
|----|---|---|---|---|
| `SYSCLK` | `set_sys_clock_khz(...)` in `hwInit()` | `src/hw.cpp` | `200000` (200 MHz) | Timing overrun at high speed — raise; re-verify clock stability and flash/SRAM access |
| `OVERSAMPLE` | `ADC_OVERSAMPLE` | `src/constants.h` | `2` | GPIO10 pulse too wide — drop to `1`; current waveform noisy — raise (watch timing budget) |
| `SAMPLE-INSTANT` | ADC burst placement in `controlStep` | `src/foc.cpp` `controlStep()` | Wrap-aligned (start of ISR) | Current spikes on scope indicate sampling lands on switching edge — shift the burst call toward PWM center |
| `KP` / `KI` | `KP_D`, `KP_Q`, `KI` (derived from `BANDWIDTH * PHASE_LD/LQ/R`) | `src/constants.h` | `3.79` / `8.28` / `4042` | Oscillation → lower; sluggish tracking → raise; adjust via `BANDWIDTH` and let the `constexpr` derivation recompute both axes |
| `BANDWIDTH` | `BANDWIDTH` | `src/constants.h` | `1000` (rad/s) | Primary knob for PI response speed; change this and `KP_D`/`KP_Q`/`KI` follow automatically |
| `MOTOR_AMPS` | `MOTOR_AMPS` | `src/constants.h` | `0.9` A | Fixed q-axis current for every closed-loop move, and not exposed to the API. Lower it to buy top speed (`rpm * iq ~ 280` on a 12 V bus), raise it for torque at the cost of that ceiling |
| `DECOUPLE_FRAC` | `DECOUPLE_FRAC` | `src/constants.h` | `1.0` | Cross-coupling feedforward strength; set `0.0` to A/B test whether it helps this machine |
| `IMAX_A` | `IMAX_A` | `src/constants.h` | `1.1` A | Current sense full-scale range; changes only if the shunt or amplifier gain does. **Documentation only — nothing in `src/` reads it and there is no clamp.** The command is the fixed `MOTOR_AMPS` |
| `ADC_VREF` | `ADC_VREF` | `src/constants.h` | `3.3` V | Measured ADC reference differs from 3.3 V (use a multimeter on the AVDD pin) |
| `VBUS_V` | `VBUS_V` | `src/constants.h` | `12.0` V | Startup fallback only — the live bus comes from the ADS1015. Update if the supply is not 12 V |
| `ISENSE-SIGN` | Swap `ADC_SOA_*`/`ADC_SOB_*` channels or negate | `src/adc.cpp` `adcSampleMotor()` | As wired (SOA = phase A, SOB = phase B) | Current polarity inverted vs. expectation from Phase 1 |
| `PH-DIR` | Sign of `duty_signed` in `pwmSetPhase` | `src/pwm.cpp` `pwmSetPhase()` | Positive duty → PH high | Motor spins opposite to commanded direction |
| `LED-POL` | `ledDuty` active-low inversion | `src/foc_math.cpp` `ledDuty()` | Active-low (inverted) | Board turns out to have common-anode LED or opposite polarity convention |
| `CMD-DT` | `delayMicroseconds(500)` in the open-loop phase sketches | `bringup/phase1b_motor.h`, `phase2_openloop.h` | 500 µs | Rate at which core0 updates the open-loop commanded angle — reduce for a smoother field. Does not apply to phases 3 and 4: there the control ISR generates the angle from the profile, so core0 timing cannot reach it |
| `FLASH-TIMING` | Mark ISR chain `__not_in_flash_func` | `src/foc.cpp` `controlStep` and hot callees in `src/foc_math.cpp`, `src/pwm.cpp`, `src/adc.cpp`; `Profile::at` is `always_inline` in `src/profile.h` so it lands in `controlStep`'s own RAM section | Applied | GPIO10 pulse width is wide or jittery even after OVERSAMPLE/SYSCLK tuning — this indicates XIP flash-cache misses adding latency. Apply `__not_in_flash_func` to `controlStep` and the functions it calls (`adcSampleMotor`, `pwmSetPhase`, `piStep`, `park`, `inversePark`). This is a structural change, not a constant, so verify by re-scoping GPIO10 after applying it. |
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

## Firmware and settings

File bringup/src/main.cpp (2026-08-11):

#include <Arduino.h>
#if PHASE == 1
  #include "../phase1_hw.h"
#elif PHASE == 11  // phase1b
  #include "../phase1b_motor.h"
#elif PHASE == 12  // phase1c: stationary-frame PI (no dq transforms)
  #include "../phase1c_stationary_pi.h"
#elif PHASE == 2
  #include "../phase2_openloop.h"
#elif PHASE == 3
  #include "../phase3_foc.h"
#elif PHASE == 4
  #include "../phase4_full.h"
#elif PHASE == 5  // R/L characterization
  #include "../phase5_rl.h"
#endif

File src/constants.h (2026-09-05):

#pragma once
#include <cstdint>

namespace rotev {

enum Motor : uint8_t { MOTOR_1 = 0, MOTOR_2 = 1 };
enum Button : uint8_t { BTN_STOP = 0, BTN_GO = 1 };

// --- Motor 14HS11-1004 ---
constexpr int POLE_PAIRS = 50;      // 1.8 deg/step -> 200 steps/rev
// R and L are MEASURED on hardware (bringup phase 5), not datasheet values:
// the datasheet's 3.5 ohm / 3.5 mH are both wrong, and this motor is strongly
// salient (Lq = 2.2 * Ld), so one inductance cannot describe both axes.
// Ld < Lq is expected: the magnet sits in the d-axis flux path with mu_r ~ 1,
// so the d-axis is the high-reluctance one.
//   R  : 6-point V/I sweep regressed as I vs V, so the slope excludes the
//        driver dead-time drop and the sense offset (both land in the
//        intercept). Cross-checked three ways within 0.5%.
//   Ld : step response with the rotor parked on phase B, which makes B the
//        d-axis so the step makes no torque and the rotor cannot move.
//        R^2 0.998+, repeatable to 0.01%.
//   Lq : slope of ud vs (we*iq) over a 100-300 RPM sweep on the running
//        machine -- standstill cannot measure it, since any q-axis current
//        makes torque. R^2 0.9999, good to about +-5%.
// Values below are the mean of two motors (they agreed to within R 1.6%,
// Ld 1.5%, Lq 3.6%), which halves the worst-case error since constants.h is
// global and both axes run off it:
//     motor 1: R 4.0744  Ld 3.8231 mH  Lq 8.4265 mH
//     motor 2: R 4.0089  Ld 3.7660 mH  Lq 8.1263 mH
// The runtime does not lean on PHASE_LQ for the derate: that uses a per-motor
// ONLINE estimate (s_lq in foc.cpp) which follows each motor's saturation
// curve. PHASE_LQ only seeds it and sets KP_Q and the decoupling feedforward.
//
// Speed/current trade: the drive runs out of ud = -we*Lq*iq long before uq
// (uq measured 0.8 V at 300 RPM and falling), so the ceiling is where |ud|
// reaches the bus. Measured at 0.5 A: 560 RPM on a 12.12 V bus, i.e.
//        rpm_max * iq ~= 280        on a 12 V bus
// The only levers on it are less current, more bus, or a smaller Lq. Lq is
// characterised at 0.5 A only and iron saturates, so Lq(I) should fall at
// higher current, making the high-current ceiling better than that predicts.
constexpr float PHASE_R  = 4.0417f;     // ohms, mean of 2 (datasheet: 3.5)
constexpr float PHASE_LD = 0.0037946f;  // H, mean of 2 (datasheet: 3.5 mH)
constexpr float PHASE_LQ = 0.0082764f;  // H, mean of 2 -- sets ud at speed

// Fixed q-axis current for every closed-loop (profile) MOVE. Not exposed: the
// trade above makes current a tuning knob for the drive, not for the user.
// Standstill uses MOTOR_HOLD_AMPS instead -- see below.
//
// 0.9 A is bounded by TOUCH TEMPERATURE, not by the motor. Dissipation is
// |i|^2 * R_winding (sinusoidal drive: the two phases carry cos and sin, so
// the sum of squares is constant -- NOT 2*|i|^2*R).
//
// R_winding is NOT PHASE_R. PHASE_R = 4.0417 is winding + Rds(on) + shunt, and
// the driver's ~0.23 ohm share heats the PCB, not the motor. Winding alone is
// ~3.81 ohm (PHASE_R minus the ~0.23 ohm driver share), vs 3.5 datasheet cold
// value. Using the datasheet 3.5 here UNDERSTATES motor heating by 9%.
//
// At 3.81 ohm: 0.9 A -> 3.09 W -> ~50 C surface at 25 C ambient, which is
// slightly OVER the ~48 C IEC 62368-1 prolonged-contact limit for metal.
// 0.85 A would land on it. This is only acceptable because the standstill hold
// below cuts the AVERAGE well under the limit -- a continuous-motion duty cycle
// would not be covered. MEASURE the surface before shipping; the thermal
// resistance here is a datasheet figure, and mounting dominates it.
//
// Also note the current sense: the INA181 specifies gain error only for
// V_OUT in [0.5, V_S-0.5], which at 1.5 V/A is +-0.767 A. 0.9 A is outside
// that window, so gain error at the current peaks is unspecified -- it shows
// up as waveform distortion, i.e. torque ripple. Fix that before going higher.
constexpr float MOTOR_AMPS = 0.9f;

// --- Control (PI pole placement, per axis) ---
// Each axis places its controller zero on its own plant pole: the d-axis
// plant is 1/(Ld*s + R) with a pole at -R/Ld, so the zero must sit at
// KI/KP_D = R/Ld, which falls out of KP_D = BW*Ld with a SHARED KI = BW*R.
// The same holds for q. So KP differs per axis and KI does not.
constexpr float BANDWIDTH = 1000.0f;         // rad/s, both axes
constexpr float KP_D = BANDWIDTH * PHASE_LD; // 3.79
constexpr float KP_Q = BANDWIDTH * PHASE_LQ; // 8.28
constexpr float KI   = BANDWIDTH * PHASE_R;  // 4042
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

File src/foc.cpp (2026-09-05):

#include "foc.h"
#include <cmath>
#include "pwm.h"
#include "adc.h"
#include "adc_ext.h"
#include "hw.h"
#include "debug.h"
#include "hardware/pwm.h"
#include "hardware/irq.h"
#include "hardware/sync.h"
#include "pico/multicore.h"

namespace rotev {

enum Mode : uint8_t { MODE_OFF = 0, MODE_PROFILE, MODE_VOLTAGE, MODE_AB };

// Everything core0 hands to the control ISR, and the progress it hands back.
// Guarded by s_lock rather than volatile: the profile evaluation below has to
// read and write several fields as one consistent set.
struct Setpoint {
  Mode     mode;
  bool     enabled;
  float    theta_mech;   // commanded mechanical angle, [0, 2*pi)
  float    uq;           // MODE_VOLTAGE: q-axis volts
  float    va_duty;      // MODE_AB
  float    vb_duty;      // MODE_AB
  Profile  prof;         // MODE_PROFILE
  bool     cruise;       // MODE_PROFILE: ignore prof, hold cruise_vel forever
  float    cruise_vel;   // rad/s
  uint32_t ticks;        // control ticks since the profile started
  ProfileState prog;     // published progress
};

static Setpoint s_sp[2];
static volatile AB s_tel[2]  = {{0,0},{0,0}};
// Applied dq voltage and measured dq current, for bringup telemetry. Written
// post-clamp so it reflects what actually reached inversePark().
static volatile DQ s_telu[2] = {{0,0},{0,0}};
static volatile DQ s_teli[2] = {{0,0},{0,0}};
// Published inside the same locked write as s_telu/s_teli, so a caller polling
// several getters cannot pair trim from one tick with ud from the next. The
// s_trim/s_iqcmd working copies are ISR-private and must not be read directly.
// NOTE: each getter still takes the lock separately, so this gives per-value
// coherence, NOT cross-getter atomicity -- a caller reading trim then ud can
// still straddle two ticks. Use focTelemetryI/U for the pairs that must match.
static volatile float s_teltrim[2] = {1.0f, 1.0f};
static volatile float s_teliqc[2]  = {MOTOR_HOLD_AMPS, MOTOR_HOLD_AMPS};
// s_lq itself, published. Without this the estimator is UNOBSERVABLE: the only
// external proxy is |ud|/(we*iq) from telemetry, and that ud is written after
// the backstop while the estimator's is read before it -- they differ by
// exactly the clip, which is largest when the estimate matters most.
static volatile float s_tellq[2]   = {PHASE_LQ, PHASE_LQ};
static PIState s_pid[2], s_piq[2];
static float   s_lq[2] = {PHASE_LQ, PHASE_LQ};  // online Lq, tracks saturation
// Saturation trim on the derate, plus its two input filters. See constants.h.
static float   s_trim[2]  = {1.0f, 1.0f};
static float   s_sat[2]   = {0.0f, 0.0f};   // backstop duty cycle
// Slewed q-axis current command, so the move/hold transition is not a step.
static float   s_iqcmd[2] = {MOTOR_HOLD_AMPS, MOTOR_HOLD_AMPS};
static float   s_donefor[2] = {0.0f, 0.0f};   // seconds the axis has been done
// Previous tick's backstop flag. Gates the s_lq estimator: the FILTERED duty
// was far too blunt -- s_sat < 0.02 means fewer than 2% of ticks clipped, which
// on the validation run shut the estimator out of 90% of windows above 400 RPM,
// exactly where s_lq is the only thing making the derate correct.
static bool    s_satprev[2] = {false, false};
static float   s_vbad[2] = {0.0f, 0.0f};  // seconds of invalid vbus
// Latched on a vbus fault, cleared only by focEnable(). A fault is a safety
// state with no other observability -- see motorFault().
static volatile bool s_fault[2] = {false, false};
static spin_lock_t* s_lock;
static volatile int s_turn = 0; // 0 -> motor1, 1 -> motor2
// Pre-computed duties applied at the very start of the next ISR invocation,
// before any slow computation, to minimize CC-register latency from the PWM wrap.
static float s_next_a[2] = {0, 0};
static float s_next_b[2] = {0, 0};

// One control period per motor: the wrap IRQ fires at PWM_HZ and alternates
// motors, so each motor is serviced at PWM_HZ/2.
static constexpr float CTRL_DT = 1.0f / (PWM_HZ / 2.0f);
static constexpr float TWO_PI_F = 6.28318530717958647692f;
// Largest tick count that (float)ticks still represents exactly.
static constexpr uint32_t TICKS_MAX = 1u << 24;

// per-motor pin sets
static void phasePins(Motor m, uint32_t& phA, uint32_t& phB) {
  if (m == MOTOR_1) { phA=PIN_PHA_1; phB=PIN_PHB_1; }
  else              { phA=PIN_PHA_2; phB=PIN_PHB_2; }
}
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

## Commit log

2026-07-01 Add RotEv2 FOC library design spec
    Brainstormed design covering framework (arduino-pico + Pico SDK internals),
    dual-core FOC (core1) / user code (core0), float+sinf/cosf numerics,
    center-aligned 24kHz PWM, oversampled center-window ADC sampling,
    PI + lag-comp control, public rotev:: API, and 4-phase bringup plan.
2026-07-01 Resolve LED polarity, Vref, and modulation naming in design spec
    LED is active-low (PWM drives cathodes); ADC Vref confirmed 3.3V;
    clarified modulation is direct alpha-beta phase-voltage application,
    not SVPWM (which is 3-phase BLDC only).
2026-07-01 Add RotEv2 FOC library implementation plan
    18 tasks: scaffolding + native-tested foc_math, hardware modules
    (hw/led/button/debug/pwm/adc), core1 FOC loop, public rotev:: API,
    4-phase bringup sketches + BRINGUP.md, README/packaging.
2026-07-01 feat: PI controller with output clamp and anti-windup
2026-07-01 feat: electrical angle, omega estimator, ADC scaling, active-low LED duty
2026-07-01 test: assert omega priming-returns-zero and ledDuty midpoint
2026-07-01 feat: hw module - clock, pin init, nSLEEP control
2026-07-01 feat: active-low RGB LED PWM module
2026-07-01 feat: debounced button reads (active-high, pull-down)
2026-07-01 feat: loop-timing debug pin (guarded by ENABLE_LOOP_TIMING)
2026-07-01 feat: center-aligned 24kHz PWM with per-phase PH/EN voltage output
2026-07-01 feat: oversampled 2-channel current sampling with counts->amps
2026-07-01 feat: core1 FOC loop - PWM-wrap ISR, alternating motors, PI + lag comp
2026-07-01 fix: guard s_lagcomp with spinlock for correct cross-core visibility
    [foc.cpp]
2026-07-01 docs: README with API, GPIO map, dual-core contract, motor/tuning specs; add example + keywords
2026-07-01 docs: fix README technical inaccuracies from review
    - DRV8874 (not DRV8825); no Clarke transform (Park only)
    - motorWrite amps is q-axis (torque) current, Id held at 0
    - LED mapping corrected (255 = full brightness, 0 = off)
    - fill lib_deps with the repo git URL
2026-07-01 fix: broaden library.properties architectures; align ledDuty tests to LED_TOP
    [test_main.cpp]
2026-07-12 maybe fix phase 1c?
    [led.cpp]
2026-07-12 Fix leds
2026-07-13 Fix high rpm control
    [foc.cpp]
2026-07-13 Switch both motors to locked-antiphase PWM (GPIO0-3)
    EN is now hardwired HIGH on all 4 DRV8874s (next PCB rev) instead of
    GPIO-controlled; PH is PWMed at duty=(1+d)/2 so current is always
    actively driven rather than coasting, which is the decay behavior
    FOC needs. Consolidates motor PWM onto GPIO0-3 (2 slices instead of
    4), freeing GPIO4-7 as spare general-purpose pins.
    Removes the now-dead sign-magnitude (EN-PWM) code path entirely and
    folds in the fix for a bug found while validating this on motor 1
    (gpio_set_function's side effect on cfgEn's EN pin silently
    overrode the intended static-HIGH GPIO state).
    [constants.h, foc.cpp, hw.cpp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]
2026-07-13 Fix unbounded angle into sinf/cosf causing variable ISR latency
    electricalAngle() fed the ever-accumulating mechanical position straight
    into park()/inversePark(), so during a long multi-rotation profile the
    electrical angle grew to tens of thousands of radians. sinf/cosf range
    reduction for large arguments is data-dependent, which showed up on
    GPIO10 as ISR pulse width drifting (18-24us) instead of staying constant.
    Wrap the electrical angle to (-PI, PI]; omegaStep()'s velocity estimate
    is fixed to diff the wrapped angle by its shortest path instead of a
    raw subtraction, since a plain diff would otherwise see a false ~2*PI
    jump every time the wrap boundary is crossed.
    Also mark controlStep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
    [adc.cpp, foc.cpp, foc_math.cpp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]
2026-07-13 Add design spec for buzzer, ADS1015 ADC, and GPIO renumbering
    Incorporates the PRD updates (buzzer, external ADC, pin shifts) into
    the library architecture: automatic background-timer ADC scheduling,
    dedicated buzzer PWM slice, and live Vbus feeding the FOC loop.
2026-07-13 Add Phase 1 buzzer tune + bus voltage display to spec and bringup guide
    GO press now plays an audible buzzer smoke test in addition to the LED
    color change, and Phase 1 telemetry gains busVoltage() so it can be
    checked against a multimeter reading before later phases depend on it.
2026-07-13 Add implementation plan for buzzer, ADS1015 ADC, and GPIO renumbering
2026-07-13 Update GPIO pin map for buzzer/ADC, add new constants
    [constants.h]
2026-07-13 Add buzzer clamp and ADS1015 conversion/sequencing math with tests
    Pure math helpers for:
    - buzzClampFreq: clamp buzzer frequency to BUZZ_MIN_HZ..BUZZ_MAX_HZ
    - adsRawToVolts: convert ADS1015 12-bit left-justified samples to voltage
    - dividerToVbus: undo bus voltage divider (7.3k/2.2k) to recover actual voltage
    - adcSeqChannel: weighted round-robin ADS1015 channel sequencing (AIN0 gets 2/3)
    - adcConfigForChannel: generate ADS1015 config register for single-shot conversion
    All 9 tests pass (26 total).
    [foc_math.cpp, test_main.cpp]
2026-07-13 Add buzzer module and public buzzerOn/buzzerOff API
    [buzz.cpp, rotev.cpp]
2026-07-13 Add ADS1015 driver with background sampling and public adcRead/busVoltage API
2026-07-13 Feed live ADS1015 bus voltage into the FOC control loop
2026-07-13 Add buzzer tune and bus voltage telemetry to Phase 1 bringup
2026-07-13 Document buzzer, external ADC, and live bus voltage in README
2026-07-13 Fix init-ordering race between adcExtInit() and focStart()
    focStart() launches core1, which immediately starts calling
    adcExtVbus() from the PWM-wrap ISR every control cycle. That call
    needs adc_ext's spinlock and cached vbus value already initialized,
    so adcExtInit() must run before focStart() in begin(). Also updates
    a stale VBUS_V comment and corrects a 2047->2048 typo in the ADS1015
    counts-to-volts formula in the design spec (implementation was
    already correct).
    [constants.h, rotev.cpp]
2026-07-13 Remove lag compensation and its bus-voltage-circle scaling helper code
    Lag compensation didn't work correctly and isn't needed since velocity
    doesn't change fast enough within an S-curve profile to matter. Removes
    the feedforward terms, the omega estimator that fed them (OmegaEst/
    omegaStep/omegaReset, no longer used elsewhere), and the setLagComp/
    focSetLagComp API. The independent ud/uq bus-voltage-circle clamp is
    kept since it's needed regardless of lag comp to prevent inversePark's
    per-phase duty clamp from distorting the dq split.
    [foc.cpp, foc_math.cpp, rotev.cpp]
2026-08-11 Holy crap i hit 1700rpm
2026-08-11 Add 2nd motor
2026-08-11 Add 2nd motor whoops
2026-08-11 Add S-curve Profile class with unit tests
    Raised-cosine velocity ramps so acceleration starts and ends at zero, giving
    a closed form cheap enough to evaluate in the control ISR. Four construction
    routes: distance+vmax+amax, distance+time+amax, and vertical/horizontal
    stretches of an existing profile.
    47/47 native tests pass.
2026-08-11 Make the profile trapezoidal in velocity, not raised-cosine
    Per user: "S curve" refers to the shape of the POSITION curve, which the
    integral of a trapezoidal velocity ramp already gives. Constant-acceleration
    ramps also cost 1/(pi/2) less ramp time for the same torque.
    ta = V/A; triangular branch peaks at sqrt(A*D); fromTimeAccel solves
    v^2/A - T*v + D = 0. Header contract and all callers unchanged.
    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
2026-08-11 Rewrite motor API around profiles; simplify FOC, bringup and docs
    Public API is now begin/motorEnable/motorSetProfile/motorProfile/motorProgress
    plus board I/O. Current is fixed at MOTOR_AMPS 0.8 A and not exposed. The
    control ISR executes the profile itself, so the caller no longer integrates a
    position or feeds velocity/accel per iteration.
    Deleted: motorWrite/WriteVelocity/WriteProfile/WriteVoltage/WriteVoltageAB,
    motorDisable, motorDerate, the caller-timestamp extrapolation (PROF_TRACK,
    PROF_ACC_FF, PROF_AGE_MAX_US) and the differenced speed estimator (WE_ALPHA,
    WE_TIMEOUT_S) -- no surviving mode needs them. Open-loop voltage and
    telemetry primitives moved to the undocumented rotev_inte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
    [Basic.ino, constants.h, foc.cpp]
2026-08-11 Fix defects found in review
    Profile:
    - fromTimeAccel used v = A*(T-sqrt(T*T-4D/A))/2, which cancels
    catastrophically for T well above the minimum time. fromTimeAccel(0.1, 300,
    100) returned an EMPTY profile -- silent zero motion -- for a request 4700x
    above Tmin, and a randomized sweep put 5.7% of reachable requests off by
    more than 1%. Use the algebraically identical 2D/(T+sqrt(disc)), which has
    no subtraction. Two regression tests added.
    - at() was out-of-line in XIP flash and reached from the RAM-resident control
    ISR through a veneer, inside the setpoint spinlock: a cache miss there
    stretches a 24 kHz tick and the lock core0 is waiting on. Moved into the
    header and forced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
    [constants.h, foc.cpp, foc_math.cpp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]
2026-08-11 Update docs to match the new API
    BRINGUP.md: IMAX_A is the sense range, not a command clamp -- nothing clamps a
    current command any more; the FLASH-TIMING knob is applied, not pending, and
    now covers Profile::at; phase 3's print description matched neither the fields
    it emits nor what is observable from them; CMD-DT no longer applies to
    phase 1c; RAM/Flash figures refreshed.
    PRD.md: the FOC API section still specified motorWrite/motorWriteVelocity/
    motorWriteProfile as the requirement, and several source files point readers
    at it. Rewritten around motorSetProfile and the reason the profile has to be
    computed inside the tight loop. Telemetry marked internal.
    README.md: user ADC channels ref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
2026-08-11 Keep reported progress on disable; only rewind the clock
    Resetting prog too made a finished-then-disabled axis read back as position
    0, which is exactly what phase 4 prints after each leg. Rewinding the tick
    counter is what prevents the unsafe mid-cruise resume; the published state
    should still say where the axis stopped.
    [foc.cpp]
2026-08-11 Chirp the buzzer when a leg lands in the Basic example
    [Basic.ino]
2026-08-11 Fix basic example and profile printing
    [Basic.ino, profile.cpp]
2026-08-12 Add resources
    [14HS11-1004S.STEP, NylonBall.step, rotev2.step]
2026-08-12 Add asymmetric profiles, multi-leg scheduling and unit printing
    Profile now stores its ramp-down time separately, so accel and decel no
    longer have to match. fromAccelDecel() and fromTimeAccelDecel() are the
    asymmetric complements of the existing two factories; the symmetric ones
    call through to them with the same rate twice, so their behaviour is
    unchanged by construction.
    fromLegs() solves a whole sequence at once: given a list of legs and a
    time budget, it finds the single cruise velocity that makes the legs take
    exactly that long and writes out one profile each. A leg too short to
    reach that velocity pins triangular and stops responding to it, which the
    closed-form quadratic cannot see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
    [profile.cpp, test_main.cpp]
2026-08-12 Hold position on motorEnable, with no profile required
    An axis that had never been given a profile was still MODE_OFF, so
    enabling it released nSLEEP and then left the shaft free to be turned by
    hand. Enabling now promotes MODE_OFF to a standstill hold: an empty
    profile evaluates to zero velocity for all t, so theta_mech never
    advances and the axis energises at its current commanded angle. That is
    the path the ISR already takes once a move finishes, not a new mode, and
    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
2026-09-05 Reduce standstill current, raise move current, add a saturation trim
    Three changes to the closed-loop current path, plus the telemetry to see them.
    MOTOR_AMPS 0.8 -> 0.9 A, and a separate MOTOR_HOLD_AMPS = 0.4 A for standstill.
    focEnable() promotes an axis with no profile to a hold and a finished move holds
    too, so the drive previously burned full current while parked -- most of the
    duty cycle on a robot. Measured +11% current delivered at 150-425 RPM against
    what the old constants allowed at matched speed and bus voltage.
    The hold is bounded by TOUCH TEMPERATURE, not by the motor: dissipation is
    |i|^2 * R_winding (sinusoidal drive -- the phases carry cos and sin, so the sum
    of squares is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
    [constants.h, foc.cpp, rotev.cpp]
2026-09-05 Fix latches and faults found by adversarial review; add motorFault()
    Follow-up to 3592ee5. Five review rounds against that commit found defects in
    it and, repeatedly, in the fixes for the round before -- so read the reasoning
    here, not just the diff.
    ESTIMATOR. The s_lq update is now gated on |id| < LQ_EST_MAX_ID and nothing
    else. Its derivation -- holding id at 0 against a rotating current vector
    requires exactly ud = -we*Lq*iq -- is valid only WHEN id ACTUALLY IS 0, and
    every latch this loop suffered came from learning while it was not. Gating on
    the backstop instead stranded s_lq LOW (a low estimate over-permits iq_max,
    which saturates, which closes the gate, which cannot recover). "Esca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
    [adc_ext.cpp, constants.h, foc.cpp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]
